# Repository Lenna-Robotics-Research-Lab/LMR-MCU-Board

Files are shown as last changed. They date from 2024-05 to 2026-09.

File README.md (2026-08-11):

# LMR Bardia MCU Board

Open-source control electronics and embedded software for the **Lenna Mobile Robot ONE (LMR v1.1)**, developed by [Lenna Robotics Research Lab](https://github.com/Lenna-Robotics-Research-Lab).

The Bardia board is built around the STM32F407VGT6 and combines motor control, encoder feedback, sensor interfaces, power management, and host-computer communication on one mobile-robotics platform.

<p align="center">
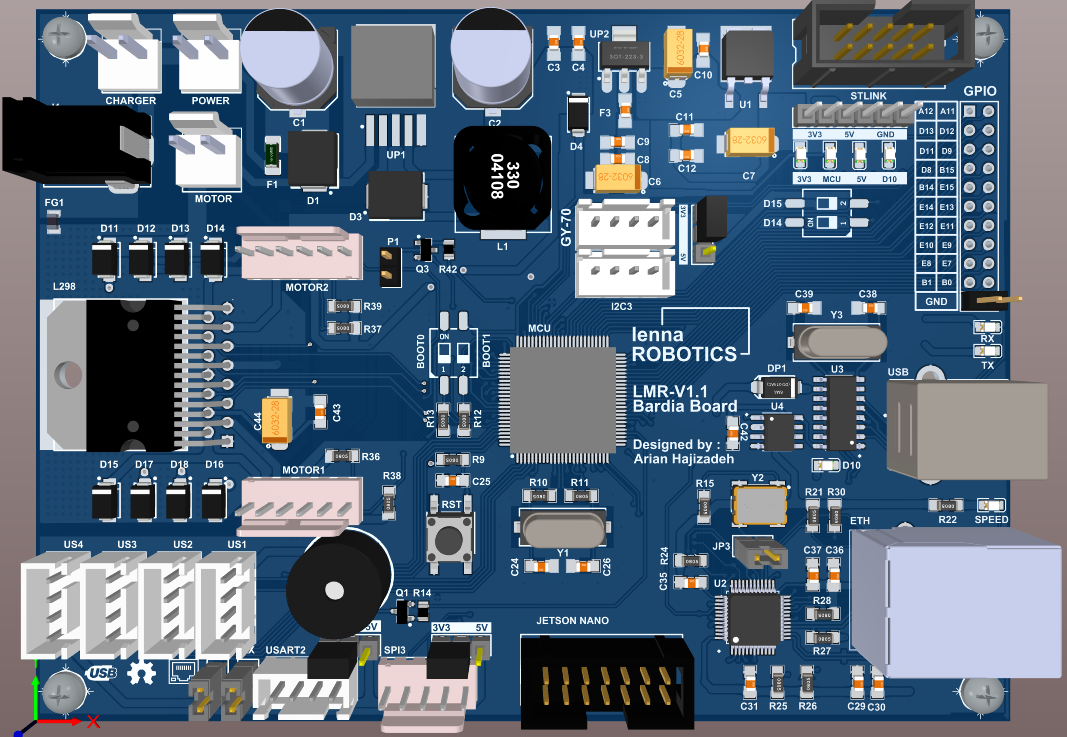
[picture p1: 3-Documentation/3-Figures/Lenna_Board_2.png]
Top view of the LMR Bardia MCU board
  
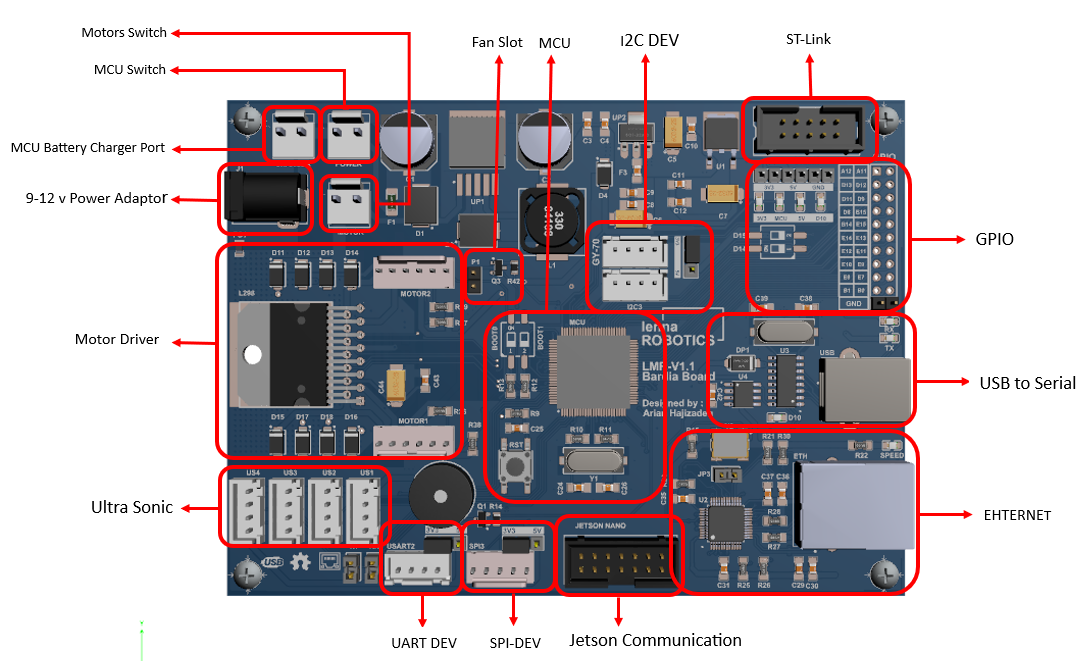
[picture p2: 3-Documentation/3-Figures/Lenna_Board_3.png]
Angled view of the LMR Bardia MCU board
  
</p>

## Contents

- [Main features](#main-features)
- [Quick navigation](#quick-navigation)
- [Repository structure](#repository-structure)
- [Hardware overview](#hardware-overview)
- [Embedded software](#embedded-software)
- [Motor identification and control](#motor-identification-and-control)
- [Host communication](#host-communication)
- [Getting started](#getting-started)
- [License](#license)

## Main features

- STM32F407VGT6 Arm Cortex-M4 microcontroller
- On-board L298 dual H-bridge motor driver
- Quadrature encoder inputs for closed-loop wheel-speed control
- CH340G USB-to-serial interface
- Simultaneous USB and battery connection through the power-management circuit
- Dedicated battery-voltage ADC input
- Dedicated cooling-fan connector
- Four HC-SR04-compatible ultrasonic sensor connectors
- Expansion interfaces:
  - 1x I2C
  - 1x UART
  - 1x SPI
  - 1x CAN
  - 20x GPIO
- Ethernet hardware based on the DP83848 physical-layer transceiver

> [!NOTE]
> Ethernet hardware is present on the board, but Ethernet is not used in the initial LMR v1.1 software release.

## Quick navigation

| Area | Location | Description |
| --- | --- | --- |
| Datasheets | [`1-Resources/1-Datasheets`](./1-Resources/1-Datasheets) | Component datasheets and hardware design references |
| MATLAB simulation | [`2-Design/2-Simulation/MATLAB`](./2-Design/2-Simulation/MATLAB) | Kinematic modelling and motor system identification |
| Altium hardware project | [`2-Design/3-Detailed-Design/1-Electronics/LMR_V1`](./2-Design/3-Detailed-Design/1-Electronics/LMR_V1) | Schematics, PCB layout, and 3D board files |
| STM32 firmware | [`2-Design/3-Detailed-Design/2-Source-Code/Lenna-Bardia-MCU-Board`](./2-Design/3-Detailed-Design/2-Source-Code/Lenna-Bardia-MCU-Board) | STM32CubeIDE project and embedded-software documentation |
| Board figures | [`3-Documentation/3-Figures`](./3-Documentation/3-Figures) | Board photographs, renders, and pinout diagram |
| License | [`LICENSE`](./LICENSE) | Repository license |

## Repository structure

The following tree shows the main project areas. Generated STM32 support files and individual datasheets are omitted for readability.

```text
LMRO-MCU-Board/
├── 1-Resources/
│   └── 1-Datasheets/                 # Component datasheets and references
├── 2-Design/
│   ├── 2-Simulation/
│   │   └── MATLAB/
│   │       ├── Kinematics-Modeling/  # Differential-drive modelling
│   │       └── System-Identification/# Motor identification and control models
│   └── 3-Detailed-Design/
│       ├── 1-Electronics/
│       │   └── LMR_V1/               # Altium schematics, PCB, and 3D models
│       └── 2-Source-Code/
│           └── Lenna-Bardia-MCU-Board/
│               ├── Core/
│               │   ├── Inc/          # Application headers
│               │   ├── Src/          # Application sources
│               │   └── Startup/      # STM32 startup code
│               ├── Drivers/          # STM32 HAL and CMSIS drivers
│               ├── Lenna-Bardia-MCU-Board.ioc
│               └── README.md         # Detailed firmware documentation
├── 3-Documentation/
│   └── 3-Figures/                    # Board images and pinout
├── LICENSE
└── README.md
```

## Hardware overview

### Microcontroller

The STM32F407VGT6 is the central controller of the Bardia board. It was selected for its processing capability, timer resources, encoder support, communication peripherals, Ethernet capability, availability, and cost.

Its peripherals allow the board to connect directly to the robot's motor driver, wheel encoders, IMU, ultrasonic sensors, battery monitor, and high-level computer.

### Motor driver

The on-board L298 dual H-bridge can drive the two DC motors used by the LMR v1.1 differential-drive base. The motor-control firmware generates PWM and direction signals, while the wheel encoders provide feedback to the PID speed controller.

For robots that require additional motors, higher current, or greater precision, an external motor-driver board is recommended.

Noise-reduction measures include:

- **Single-point ground connection:** the motor-driver ground and logic ground are joined at one point through a ferrite bead.
- **EMI reduction:** ground stitching is used around the motor-driver section of the PCB.

### USB-to-serial interface

The USB Type-B connector and CH340G interface provide a direct serial connection to a computer. This connection can be used for debugging, telemetry, and MATLAB/Octave-based experiments. USB can also power the logic circuitry when motor power is not required.

### Power management

The board supports either:

- a three-cell lithium-ion battery pack with an integrated BMS (12.6 V fully charged, 2200 mAh in the original robot); or
- a 5 V USB supply when the motors are not needed.

The power-management circuit allows the battery and USB connection to remain attached simultaneously.

### Board layout

The board pinout and connector assignments are shown below.

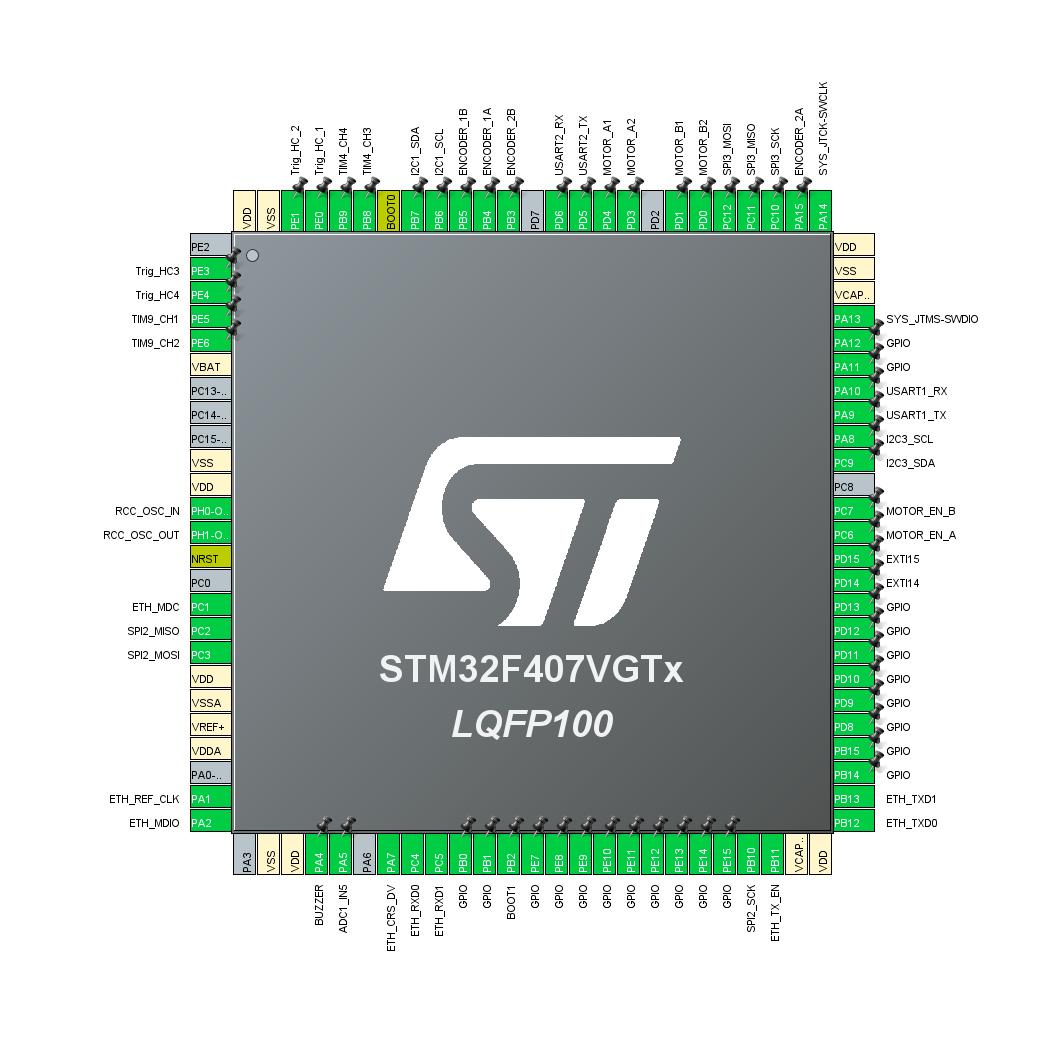
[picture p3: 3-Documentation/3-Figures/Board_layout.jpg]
LMR v1.1 Bardia board pinout


## Embedded software

The STM32 firmware is the low-level control system for the robot. It handles motor actuation, encoder feedback, odometry, IMU acquisition, ultrasonic sensing, battery monitoring, and serial communication with the high-level computer.

The complete STM32CubeIDE project and detailed module documentation are available in the [firmware directory](./2-Design/3-Detailed-Design/2-Source-Code/Lenna-Bardia-MCU-Board).

### Main firmware modules

| Module | Purpose |
| --- | --- |
| `main.c` | Peripheral initialization and application scheduling |
| `motion.c` / `motion.h` | PWM and direction control for the differential-drive motors |
| `pid.c` / `pid.h` | Closed-loop wheel-speed PID controller |
| `odometry.c` / `odometry.h` | Encoder processing, wheel speed, and travelled-distance calculation |
| `imu.c` / `imu.h` | MPU-6050 and HMC5883L acquisition, calibration, and orientation estimation |
| `rosserial.c` / `rosserial.h` | Custom UART packet handling for commands and telemetry |
| `ultrasonic.c` / `ultrasonic.h` | HC-SR04 trigger, echo capture, and distance measurement |
| `mcu_config.h` | Central hardware and application configuration |
| `utilities.c` / `utilities.h` | Shared timing and helper functions |

> [!IMPORTANT]
> Public functions developed by Lenna Robotics Research Lab use the `LRL_` prefix. Private module functions may use a leading underscore, such as `_LRL_...`.

## Motor identification and control

The two ZGA25 motors can respond differently even when they share the same part number and receive the same input. Closed-loop control is therefore required to obtain consistent wheel speeds.

The controller-development workflow uses:

1. the board's USB-to-serial interface to exchange experiment data;
2. MATLAB/Simulink Desktop Real-Time for motor system identification;
3. the identified motor response to support controller design; and
4. an embedded PID controller with encoder feedback to regulate each wheel speed.

The related models are available in [`2-Design/2-Simulation/MATLAB`](./2-Design/2-Simulation/MATLAB).

## IMU

The robot uses a GY-87 module connected through I2C. The module combines an MPU-6050 accelerometer/gyroscope with an HMC5883L magnetometer. Magnetometer data provides an external heading reference that helps reduce yaw drift compared with gyroscope-only estimation.

The firmware provides dedicated initialization, calibration, sensor-reading, and complementary-filter functions in `imu.c` and `imu.h`.

## Host communication

The Bardia board communicates with the robot's high-level computer through UART. The original LMR v1.1 integration used a Jetson Nano; the interface can also be used with another compatible Jetson or Linux host.

A custom Lenna Robotics Research Lab packet protocol carries:

- wheel-speed commands from the host to the MCU; and
- encoder, odometry, IMU, ultrasonic, and board-status telemetry from the MCU to the host.

Low-level control remains on the STM32, while perception, navigation, and other computationally intensive tasks run on the high-level computer.

## Getting started

### Explore the hardware

1. Open [`LMR_V1.PrjPcb`](./2-Design/3-Detailed-Design/1-Electronics/LMR_V1/LMR_V1.PrjPcb) in Altium Designer.
2. Review the individual schematic sheets before connecting external hardware.
3. Use the [board layout](#board-layout) to verify connector pin assignments.

### Build the firmware

1. Install STM32CubeIDE.
2. Import the project from [`2-Design/3-Detailed-Design/2-Source-Code/Lenna-Bardia-MCU-Board`](./2-Design/3-Detailed-Design/2-Source-Code/Lenna-Bardia-MCU-Board).
3. Review the board configuration in `Lenna-Bardia-MCU-Board.ioc` and `Core/Inc/mcu_config.h`.
4. Build the project and flash the STM32F407VGT6 using an ST-LINK-compatible programmer.
5. Read the [firmware README](./2-Design/3-Detailed-Design/2-Source-Code/Lenna-Bardia-MCU-Board/README.md) for module-level details.

> [!CAUTION]
> Verify the supply voltage, motor wiring, encoder wiring, and connector pinout before powering the motors. USB power alone is intended for the logic circuitry, not for driving the motors.

## License

This repository is distributed under the terms in [`LICENSE`](./LICENSE).

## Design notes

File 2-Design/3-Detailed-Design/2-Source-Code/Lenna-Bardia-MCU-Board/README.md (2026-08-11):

# Lenna Mobile Robot ONE — MCU Firmware

This directory contains the embedded firmware for the **Lenna Mobile Robot ONE (LMR)** Bardia MCU Board. The application runs on an **STM32F407VGT6** and provides the robot's low-level, real-time functions:

- closed-loop speed control for two DC motors;
- quadrature-encoder odometry;
- MPU-6050 and HMC5883L sensor acquisition;
- differential-drive motor output;
- ultrasonic-sensor support;
- command and telemetry exchange with the host computer over UART.

For the board design, schematics, PCB files, and full project documentation, return to the [repository README](../../../../README.md).

## Contents

- [Firmware architecture](#firmware-architecture)
- [Runtime schedule](#runtime-schedule)
- [Project structure](#project-structure)
- [Hardware and peripheral map](#hardware-and-peripheral-map)
- [Modules](#modules)
- [Serial communication](#serial-communication)
- [Build and flash](#build-and-flash)
- [Configuration](#configuration)
- [Real-time design rules](#real-time-design-rules)
- [Debugging](#debugging)
- [Coding conventions](#coding-conventions)
- [License](#license)

## Firmware architecture

The firmware uses STM32 HAL drivers and a cooperative main loop. Hardware interrupts signal time-critical events, while command execution, control updates, and sensor acquisition are performed by application code.

```mermaid
flowchart TD
    Host["Host computer"] -->|"UART commands"| Serial["ROS-serial protocol"]
    Serial --> PID["100 Hz speed PID"]
    Encoders["Wheel encoders"] --> Odom["Odometry cache"]
    Odom --> PID
    PID --> Motors["PWM and direction"]
    IMU["GY-87 at 10 Hz"] --> Cache["IMU cache"]
    Odom --> Telemetry["ReadAll telemetry"]
    Cache --> Telemetry
    Telemetry -->|"UART response"| Host
```

The main data paths are:

1. A host command is received through USART1 or USART2.
2. The protocol handler validates the frame and updates the requested state, such as motor-speed references or PID gains.
3. TIM5 schedules the speed-control loop every 10 ms.
4. The PID module reads both encoders, updates the cached wheel measurements, and calculates the left and right motor commands.
5. The motion module applies direction GPIO states and PWM duty cycles.
6. IMU measurements are acquired separately every tenth control cycle.
7. A `ReadAll` request serializes the most recent cached odometry and IMU values without initiating new sensor reads.

## Runtime schedule

| Activity | Nominal rate | Location | Purpose |
|---|---:|---|---|
| TIM5 scheduler | 100 Hz | `main.c` | Raises the control-loop flag every 10 ms |
| Encoder and PID update | 100 Hz | `pid.c` | Measures wheel speed and updates both motor outputs |
| IMU and magnetometer acquisition | 10 Hz | `main.c`, `imu.c` | Refreshes the cached inertial measurements |
| UART reception | Event-driven | `main.c`, `rosserial.c` | Receives framed host commands using interrupts |
| Telemetry response | On request | `rosserial.c` | Sends the latest cached state |

TIM5 has a higher effective interrupt priority than the UART interfaces. Keep interrupt callbacks short and keep all blocking peripheral operations out of interrupt context.

## Project structure

```text
Lenna-Bardia-MCU-Board/
├── Core/
│   ├── Inc/                         Application and generated headers
│   │   ├── mcu_config.h             Board-level pin and protocol definitions
│   │   ├── motion.h                 Motor and differential-drive API
│   │   ├── odometry.h               Encoder and wheel-state API
│   │   ├── pid.h                    Dual-motor PID API and default gains
│   │   ├── imu.h                    MPU-6050/HMC5883L API
│   │   ├── rosserial.h              UART protocol state and commands
│   │   ├── ultrasonic.h             HC-SR04 API
│   │   └── utilities.h              Timing utilities
│   ├── Src/
│   │   ├── main.c                   Initialization, scheduler, and callbacks
│   │   ├── motion.c                 PWM and direction control
│   │   ├── odometry.c               Encoder processing
│   │   ├── pid.c                    Closed-loop wheel-speed control
│   │   ├── imu.c                    IMU, magnetometer, and filtering
│   │   ├── rosserial.c              Packet validation and dispatch
│   │   ├── ultrasonic.c             Ultrasonic measurement
│   │   └── utilities.c              Microsecond delay support
│   └── Startup/                     STM32 startup assembly
├── Drivers/                         STM32F4 HAL and CMSIS
├── .settings/                       STM32CubeIDE project settings
├── Lenna-Bardia-MCU-Board.ioc       STM32CubeMX configuration
├── STM32F407VGTX_FLASH.ld           Flash linker script
├── STM32F407VGTX_RAM.ld             RAM linker script
└── README.md                        Firmware documentation
```

Files such as `gpio.c`, `tim.c`, `usart.c`, and `i2c.c` are generated from the `.ioc` configuration. Application-specific behavior is concentrated in `main.c` and the `LRL_` modules.

## Hardware and peripheral map

| Peripheral | Assignment | Firmware use |
|---|---|---|
| STM32 | STM32F407VGT6, LQFP100 | Main controller |
| TIM2 | Encoder mode | Left wheel encoder |
| TIM3 | Encoder mode | Right wheel encoder |
| TIM8 CH1 | PWM | Right motor |
| TIM8 CH2 | PWM | Left motor |
| TIM5 | Periodic interrupt | 10 ms control scheduler |
| TIM4 | Input capture | Ultrasonic echo timing |
| TIM1 | Base timer | Microsecond delay utility |
| USART1 | 115200, 8-N-1 | On-board USB-to-serial interface |
| USART2 | 115200, 8-N-1 | Host/Jetson interface |
| I2C3 | 100 kHz | GY-87 IMU and magnetometer |
| ADC1 | Analog input | Battery-level measurement support |

The current differential-drive configuration in `main.c` uses a wheel radius of **32.5 mm**, a wheel separation of **180 mm**, and an encoder period of **48,960 counts**.

## Modules

### Motion control

[`motion.c`](Core/Src/motion.c) converts signed duty-cycle commands into motor direction and PWM output.

| Function | Purpose |
|---|---|
| `LRL_Motion_MotorSpeed()` | Controls one motor from -100% to +100% duty cycle |
| `LRL_Motion_Control()` | Applies independent left and right motor commands |
| `LRL_Motion_MotorTest()` | Runs a blocking motor test sequence for bench testing |

### PID controller

[`pid.c`](Core/Src/pid.c) contains a single controller state with independent gains and internal values for the two wheels. `LRL_PID_Update()` performs the encoder measurement, calculates both control signals, applies saturation, and supports anti-windup.

Default gains, saturation limits, and the 10 ms sampling time are defined in [`pid.h`](Core/Inc/pid.h). Gains can also be changed through the serial protocol.

### Odometry

[`odometry.c`](Core/Src/odometry.c) reads TIM2 and TIM3, handles counter wraparound, calculates signed wheel velocity, and updates incremental wheel distance.

`LRL_Odometry_ReadAngularSpeed()` owns the encoder-history update. During normal closed-loop operation it is called by `LRL_PID_Update()`, and the resulting values in `odom.vel` and `odom.dist` act as the telemetry cache.

### IMU and magnetometer

[`imu.c`](Core/Src/imu.c) supports the GY-87 module:

- MPU-6050 accelerometer and gyroscope initialization;
- accelerometer and gyroscope calibration;
- HMC5883L magnetometer initialization and heading calculation;
- complementary filtering for roll and pitch.

The main loop refreshes the IMU cache at 10 Hz. Communication functions read this cache; they do not perform I2C transactions.

### ROS-serial protocol

[`rosserial.c`](Core/Src/rosserial.c) implements the custom binary protocol used by the host-side ROS integration. Despite the module name, this is a project-specific protocol with ROS-style framing, not the standard ROS `rosserial` client library.

The module supports both configured UART interfaces through separate `rosserial_cfgType` instances.

### Ultrasonic sensors

[`ultrasonic.c`](Core/Src/ultrasonic.c) provides trigger, input-capture, overflow, and distance-reading functions for HC-SR04 sensors. The callbacks are available, but the relevant callback code in `main.c` must be enabled when ultrasonic sensing is used.

### Utilities

[`utilities.c`](Core/Src/utilities.c) provides the timer-backed `LRL_Delay_Us()` helper used for short microsecond delays.

## Serial communication

### Interfaces

| Interface | Handle | Intended connection |
|---|---|---|
| USB-to-serial | `huart1` / USART1 | Development computer |
| Host serial | `huart2` / USART2 | Jetson or another high-level controller |

Both interfaces use **115200 baud, 8 data bits, no parity, and 1 stop bit**.

### Frame format

| Byte(s) | Field | Description |
|---|---|---|
| 0 | Sync 1 | `0xFF` |
| 1 | Protocol version / Sync 2 | `0xFE` |
| 2–3 | Payload length | 16-bit little-endian length |
| 4 | Header checksum | Validates the length field |
| 5–6 | Function ID | Two-byte command identifier; current dispatch uses the low byte |
| 7…N | Command data | Function-specific payload |
| Last | Data checksum | Validates the function ID and data |

### Commands

| ID | Command | MCU behavior |
|---:|---|---|
| `0x00` | Query | Echoes the received frame for a link test |
| `0x01` | ReadAll | Returns cached wheel, IMU, and heading data |
| `0x02` | SetPID | Updates left or right PID gains |
| `0x03` | GetPID | Returns the selected motor's PID gains |
| `0x04` | MotorSpeed | Updates the signed left and right wheel-speed references |

The protocol parser validates sync bytes and both checksums. Invalid frames generate an error response. Refer to the header comment in [`rosserial.c`](Core/Src/rosserial.c) for byte-level examples.

## Build and flash

### Requirements

- STM32CubeIDE;
- an ST-LINK programmer/debugger;
- the Bardia MCU Board or equivalent STM32F407VGT6 target;
- a suitable board power supply;
- optional serial terminal for communication tests.

The repository already contains the STM32 HAL and CMSIS dependencies under `Drivers/`; no separate package installation is required.

### STM32CubeIDE workflow

1. Clone the repository:

   ```bash
   git clone https://github.com/Lenna-Robotics-Research-Lab/LMRO-MCU-Board.git
   ```

2. In STM32CubeIDE, select **File → Open Projects from File System**.
3. Select this `Lenna-Bardia-MCU-Board` directory as the project root.
4. Allow STM32CubeIDE to import the existing project configuration.
5. Select the **Debug** or **Release** build configuration and build the project.
6. Connect ST-LINK to SWDIO, SWCLK, GND, and the appropriate reference voltage.
7. Use **Run** or **Debug** to program the MCU.

Before connecting motors, verify the supply voltage, motor wiring, encoder wiring, and direction convention. For initial tests, keep the wheels raised or mechanically unloaded and ensure an emergency power-disconnect method is available.

## Configuration

| Setting | Location |
|---|---|
| Board GPIO and basic protocol constants | [`mcu_config.h`](Core/Inc/mcu_config.h) |
| MCU pins, clocks, timers, and peripheral generation | [`Lenna-Bardia-MCU-Board.ioc`](Lenna-Bardia-MCU-Board.ioc) |
| Motor mapping and robot geometry | [`main.c`](Core/Src/main.c) |
| PID gains, limits, and sample time | [`pid.h`](Core/Inc/pid.h) |
| UART selection and protocol limits | [`rosserial.h`](Core/Inc/rosserial.h) |
| IMU addresses, ranges, and filter constants | [`imu.h`](Core/Inc/imu.h) |

When regenerating code with STM32CubeMX, keep application changes inside the generated `USER CODE BEGIN` / `USER CODE END` sections. Review the generated interrupt priorities after regeneration.

## Real-time design rules

These rules are essential for stable motor control:

1. **The PID loop owns encoder sampling.** During closed-loop operation, only `LRL_PID_Update()` should call `LRL_Odometry_ReadAngularSpeed()`. Other modules consume the cached values.
2. **`ReadAll` must remain read-only with respect to sensors.** It may copy cached `odom` and `imu` fields, build a packet, and transmit it. Do not add `LRL_IMU_MPUReadAll()`, `LRL_IMU_MagReadHeading()`, or a new odometry measurement to this function.
3. **Do not perform blocking I2C work in UART callbacks.** Blocking sensor reads can delay the 10 ms control schedule and produce visible motor-speed jumps.
4. **Keep interrupt callbacks short.** Receive or store data, update a flag, and return. Perform packet dispatch and peripheral work in the main loop.
5. **Keep telemetry transmission asynchronous where practical.** `ReadAll` currently uses `HAL_UART_Transmit_IT()` so the 34-byte response does not block the controller for the full wire time.
6. **Preserve priority ordering.** TIM5 must be able to pre-empt UART handling. The application sets TIM5 to priority 1 and USART2 to priority 2; lower numbers represent higher urgency on STM32.
7. **Keep scheduled work bounded.** `pid_tim_flag` is a binary flag, so a main-loop operation that lasts longer than one 10 ms period can collapse multiple timer events into one update.

The intended ownership model is:

```text
PID update:  encoders -> odometry cache -> controller -> motor output
IMU task:    I2C sensors -> IMU cache
ReadAll:     odometry cache + IMU cache -> UART packet
```

## Debugging

### Motors jump when telemetry is requested

Check that `LRL_ROSSerial_ReadAll()` only packages cached fields. Fresh I2C or encoder acquisition in the telemetry path disturbs the controller timing.

### Motors do not move

- Confirm that TIM8 PWM channels are started.
- Confirm that a non-zero speed reference was received.
- Inspect `mypid.Ref_Vel_l`, `mypid.Ref_Vel_r`, and both control signals.
- Verify motor direction GPIOs and the external power supply.

### Wheel speed is incorrect or reversed

- Verify that TIM2 is connected to the left encoder and TIM3 to the right encoder.
- Check the encoder channel polarity and wiring.
- Confirm `MAX_ARR`, `TICK2RPM`, and the left/right direction conventions.

### Serial commands are ignored

- Confirm 115200, 8-N-1 on the host.
- Verify that the frame starts with `0xFF 0xFE`.
- Check the header and data checksums.
- Confirm that the host is connected to the intended UART.
- Inspect `err_hdl`, `packetReceived`, `headerValid`, and `dataValid`.

### IMU values do not update

- Verify the GY-87 connection to I2C3.
- Confirm sensor addresses and pull-up resistors.
- Check HAL return values during initialization and reads.
- Ensure the 10 Hz acquisition block remains enabled in `main.c`.

## Coding conventions

- Public laboratory functions use the `LRL_<Module>_<Function>` naming pattern.
- Module headers live in `Core/Inc`; implementations live in `Core/Src`.
- Configuration structures commonly use the `_cfgType` suffix; state structures use `_statetype`.
- Constants and macros use uppercase names with underscores.
- Internal module helpers may begin with an underscore, such as `_LRL_Clear_Buffer()`.
- Public functions and modules should use Doxygen-compatible comments.
- Hardware mappings belong in `mcu_config.h`, `main.h`, or the `.ioc` file rather than being duplicated throughout the application.

## License

This firmware is distributed under the repository's [GNU General Public License v3.0](../../../../LICENSE).

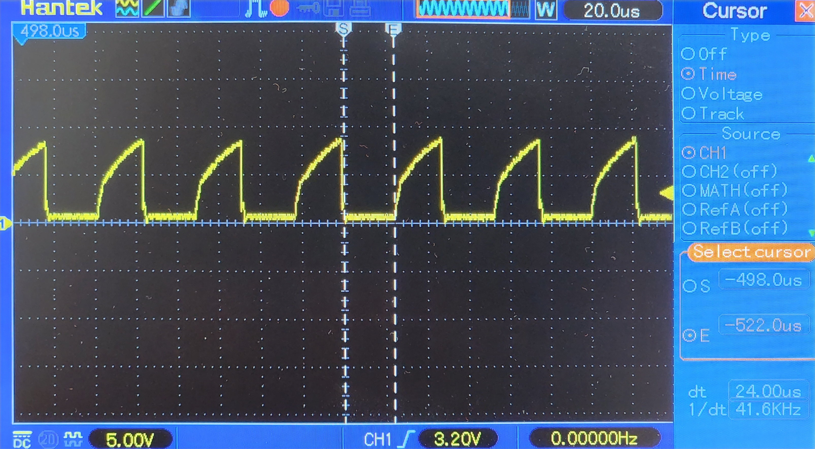
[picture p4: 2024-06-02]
2-Design/2-Simulation/MATLAB/System-Identification/pin-1-voltage.jpg

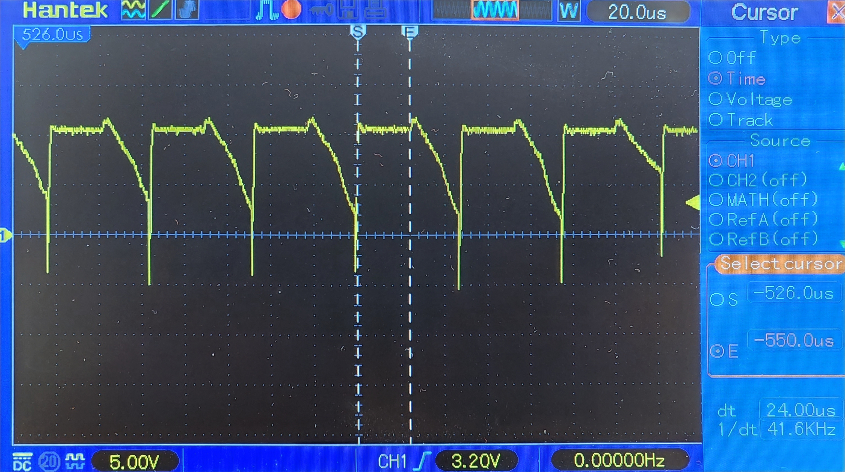
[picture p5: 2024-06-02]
2-Design/2-Simulation/MATLAB/System-Identification/pin-2-voltage.jpg

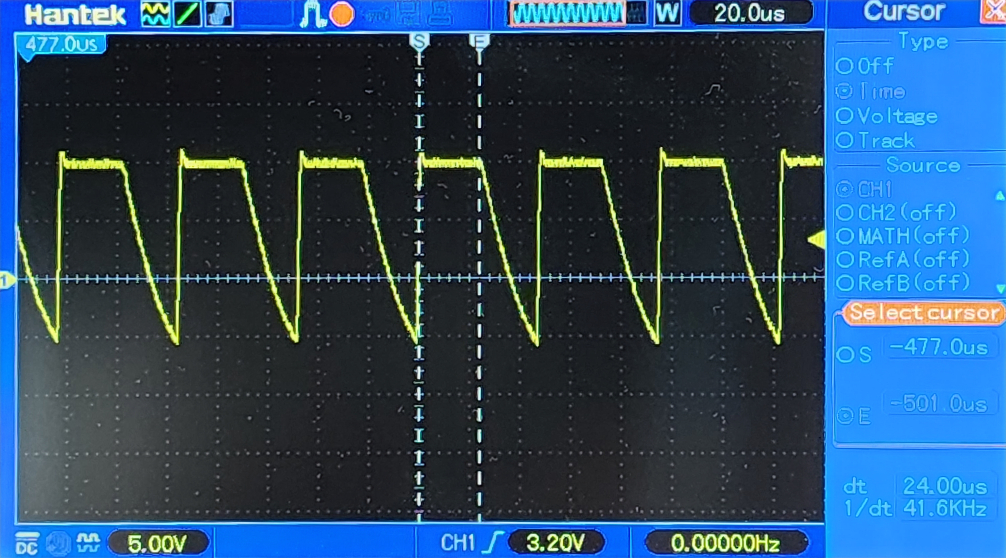
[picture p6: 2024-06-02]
2-Design/2-Simulation/MATLAB/System-Identification/motor-voltage.jpg

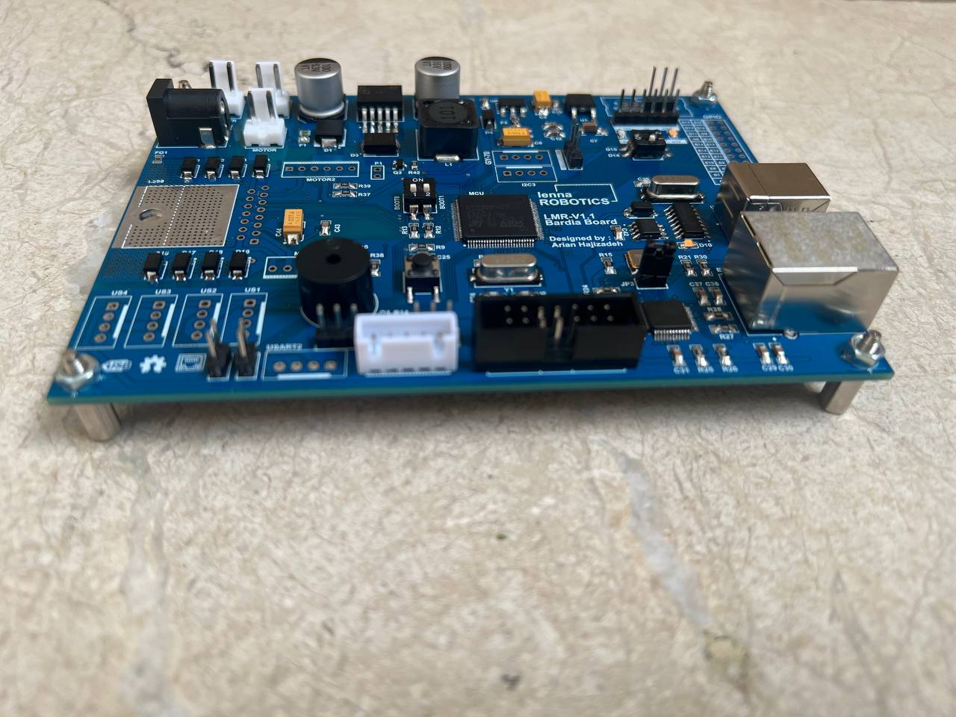
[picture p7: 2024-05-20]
3-Documentation/3-Figures/board_image.jpg

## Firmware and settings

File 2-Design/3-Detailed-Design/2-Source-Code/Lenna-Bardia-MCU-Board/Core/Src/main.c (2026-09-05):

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
/* Includes ------------------------------------------------------------------*/
#include "main.h"
#include "adc.h"
#include "eth.h"
#include "i2c.h"
#include "spi.h"
#include "tim.h"
#include "usart.h"
#include "gpio.h"

/* USER CODE BEGIN Includes */
#include "stdio.h"
#include "stdlib.h"
#include "stdbool.h"
#include "ultrasonic.h"
#include "utilities.h"
#include "motion.h"
#include "pid.h"
#include "math.h"
#include "odometry.h"
#include "mcu_config.h"
#include "imu.h"
#include "rosserial.h"



/* USER CODE END Includes */

/* USER CODE BEGIN PM */
#define PUTCHAR_PROTOTYPE int __io_putchar(int ch)

/* USER CODE END PM */


/* USER CODE BEGIN PV */

// message buffer for Initialization on High-level board
uint8_t msgBuffer[32] = " Lenna Robotics Research Lab. \r\n";

// Protocol packet size limits
uint8_t min_len_packet = 8;
uint8_t max_len_packet = 32;

//protocol Settings
//uint8_t protocol_data[144] = {0};
bool flag_uart_cb = 0;
bool flag_remain_packet = 1;

uint8_t total_pkt_length = 0;
uint8_t remain_pkt_length = 0;

unsigned short temp_crc = 0;

char MSG[64];

// LENNA for the ack
uint8_t txBuffer[144]; //= {0xFF, 0xFF, 0x05, 0xA0, 0xAB, 0xCD, 0xB4, 0xFC};



// step given by MATLAB code
uint8_t input_speed ;

// temp variables for odom
uint16_t left_enc_temp = 0, right_enc_temp = 0 , right_enc_diff = 0, left_enc_diff = 0;

// direction set
int8_t dir_right,dir_left;

//odom variables
uint16_t encoder_tick[2] = {0};
float angular_speed_left,angular_speed_right;
uint16_t tst;

uint8_t flag_tx = 0, pid_tim_flag = 0, dir_flag = 0;

uint8_t serial_flag = 0;


uint8_t test_flag = 0;


// ####################   Motor struct Value Setting   ###################
const motor_cfgType motor_right =
{
	MOTOR_PORT,
	MOTOR1_A_PIN,
	MOTOR_PORT,
	MOTOR1_B_PIN,
	&htim8,
	TIM_CHANNEL_1,
	1000,
	//1
};
const motor_cfgType motor_left =
{
	MOTOR_PORT,
	MOTOR2_A_PIN,
	MOTOR_PORT,
	MOTOR2_B_PIN,
	&htim8,
	TIM_CHANNEL_2,
	1000,
	//-1
};

// ####################   Ultra-Sonic struct Value Setting   ###################

const diffDrive_cfgType diff_robot =
{
	motor_right,
	motor_left,
	32.5,
	180
};

// ####################   ODOMETRY  ###################
const imu_cfgType gy87 =
{
	&hi2c3
};

const encoder_cfgType enc_right =
{
	&htim3,
	48960,
	0.1225f		// 6000/48960
};

const encoder_cfgType enc_left =
{
	&htim2,
	48960,
	0.1225f		// 6000/48960
};

odom_cfgType odom =
{
//	imu,
	enc_right,
	enc_left,
	diff_robot
};

imu_statetype imu =
{
	gy87
};

const ultrasonic_cfgType us_front =
{
	US1_TRIG_PORT,
	US1_TRIG_PIN,
	&htim4,
	TIM4,
	TIM_CHANNEL_3,
	168,
	1
};

// ####################   PID struct Value Setting   ###################

// definitions concerning PID gain values are made in the main.h header file

/* alternative PID
pid_cfgType2 pid_motor_left =
{
	.Kp 					= Proportional_Gain_LEFT_MOTOR,
	.Ki 					= Integral_Gain_LEFT_MOTOR,
	.Kd 					= Derivative_Gain_LEFT_MOTOR,
	.Ts 					= Sampling_Time,
	.Lower_Limit_Saturation = Lower_Saturation_Limit,
	.Upper_Limit_Saturation = Upper_Saturation_Limit,
	.Wind_Up_Amount			= 1,
};

pid_cfgType2 pid_motor_right =
{
	.Kp 					= Proportional_Gain_LEFT_MOTOR,
	.Ki 					= Integral_Gain_LEFT_MOTOR,
	.Kd 					= Derivative_Gain_LEFT_MOTOR,
	.Ts 					= Sampling_Time,
	.Lower_Limit_Saturation = Lower_Saturation_Limit,
	.Upper_Limit_Saturation = Upper_Saturation_Limit,
	.Wind_Up_Amount			= 1,
};
*/

pid_cfgType mypid;

uint8_t _pid_counter = 0; // this counter is added to reduce the effect of IMU polling temporary fix if you are not using IMU keep this 0
// ####################   Packet struct Value Setting   ###################


rosserial_cfgType ros_packet;
rosserial_cfgType usb2serial_packet;

int16_t val_x;
int16_t val_y;
int16_t val_z;
float val_heading;

uint8_t testBuffer[10]; // buffer for using test uart packet

uint8_t _temp_flag = 0;

//uint8_t protocol_buffer[256]; // the buffer used for the protocol

/* USER CODE END PV */

void SystemClock_Config(void);
/* USER CODE BEGIN 0 */

// ####################   UART Tx -> printf   ####################
PUTCHAR_PROTOTYPE
{
  /* Place your implementation of fputc here */
  /* e.g. write a character to the USART1 and Loop until the end of transmission */
  HAL_UART_Transmit(&huart1, (uint8_t *)&ch, 1, 0xFFFF);

  return ch;
}

/* USER CODE END 0 */

/**
  * @brief  The application entry point.
  * @retval int
  */
int main(void)
{
  /* MCU Configuration--------------------------------------------------------*/

  /* Reset of all peripherals, Initializes the Flash interface and the Systick. */
  HAL_Init();

  /* Configure the system clock */
  SystemClock_Config();

  /* Initialize all configured peripherals */
  MX_GPIO_Init();
  MX_ADC1_Init();
  MX_ETH_Init();
  MX_I2C1_Init();
  MX_I2C3_Init();
  MX_SPI2_Init();
  MX_SPI3_Init();
  MX_TIM2_Init();
  MX_TIM3_Init();
  MX_TIM4_Init();
  MX_TIM8_Init();
  MX_TIM9_Init();
  MX_USART1_UART_Init();
  MX_USART2_UART_Init();
  MX_TIM1_Init();
  MX_TIM5_Init();
  /* USER CODE BEGIN 2 */

  // HAL function Initializations
  HAL_TIM_PWM_Start(&htim8, TIM_CHANNEL_1);
  HAL_TIM_PWM_Start(&htim8, TIM_CHANNEL_2);
  HAL_TIM_Encoder_Start(&htim3, TIM_CHANNEL_ALL);
  HAL_TIM_Encoder_Start(&htim2, TIM_CHANNEL_ALL);
  HAL_TIM_Base_Init(&htim5);
  HAL_TIM_Base_Start_IT(&htim5);
  HAL_I2C_Init(&hi2c3);


// #################### Initializations   ####################

//  /* main code initialization

//  LRL_PID_Init(&pid_motor_left,  1);
//  LRL_PID_Init(&pid_motor_right, 1);

  HAL_GPIO_WritePin(BLINK_LED_PORT, BLINK_LED_PIN, 1);

  LRL_PID_Init(&mypid, 1);

  HAL_NVIC_SetPriority(TIM5_IRQn, 1, 0);
  HAL_NVIC_SetPriority(USART2_IRQn, 2, 0);

  LRL_Odometry_Init(&odom);

//  LRL_IMU_MPUInit(&imu);

//  LRL_IMU_MagInit(&imu);

  LRL_ROSSerial_Init(&usb2serial_packet, USB2SERIAL_UART_HANDLER);
  LRL_ROSSerial_Init(&ros_packet, JETSON_UART_HANDLER);

  HAL_GPIO_WritePin(BLINK_LED_PORT, BLINK_LED_PIN, 0);

  odom.dist.right = 0;
  odom.dist.left = 0;

  /* USER CODE END 2 */

  /* Infinite loop */
  /* USER CODE BEGIN WHILE */
  while (1)
  {
	  if(pid_tim_flag == 1)
	  {
		 if(_temp_flag == 1)
		 {
			 LRL_ROSSerial_Data_Handle(&ros_packet, &imu, &odom, &mypid);
		 }
		 else if(_temp_flag == 2)
		 {
			 LRL_ROSSerial_Data_Handle(&usb2serial_packet, &imu, &odom, &mypid);
		 }
//		 mypid.Ref_Vel_l = 150;
//		 mypid.Ref_Vel_r = 150;
		 LRL_PID_Update(&mypid, &odom);
		 LRL_Motion_Control(diff_robot, mypid.Control_Signal_l,mypid.Control_Signal_r);

//		 if(_pid_counter == 10){
//			 _pid_counter = 0;
//		     LRL_IMU_MPUReadAll(&imu);
//		     LRL_IMU_MagReadHeading(&imu);
//		     if(!odom.is_pid)
//		     {
//		     	LRL_Odometry_ReadAngularSpeed(&odom);
//		     }
//		 }

		 /* Alternative version for PID
		 LRL_Odometry_ReadAngularSpeed(&odom);
		 LRL_PID_Update(&pid_motor_left, odom.vel.left, 70);
		 LRL_PID_Update(&pid_motor_right, odom.vel.right,70);
		 */

		 /*motor test
		 LRL_Motion_MotorTest(diff_robot);
		 */

		 pid_tim_flag = 0;
	  }

    /* USER CODE END WHILE */

    /* USER CODE BEGIN 3 */
  }
  /* USER CODE END 3 */
}

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
/* USER CODE BEGIN 4 */

// CRC

// ####################   Ultra Sonic Callback   ####################

/*
void HAL_TIM_IC_CaptureCallback(TIM_HandleTypeDef *htim)
{
	// TIMER Input Capture Callback
	LRL_US_TMR_IC_ISR(htim, us_front);
}
*/

// ####################   UART Receive Callback   ####################

void HAL_UART_RxCpltCallback(UART_HandleTypeDef *huart){

	if(huart == ros_packet.huart)
	{

		LRL_ROSSerial_Rx(&ros_packet);
		_temp_flag = 1;
	}
	else if  (huart == usb2serial_packet.huart)
	{
		LRL_ROSSerial_Rx(&usb2serial_packet);
		_temp_flag = 2;
//	HAL_GPIO_WritePin(BLINK_LED_PORT, BLINK_LED_PIN, 1); // this is for testing purposes
	}



}

// ####################   Timer To Creat 0.01 Delay Callback   ####################

void HAL_TIM_PeriodElapsedCallback(TIM_HandleTypeDef* htim){
	if(htim == &htim5)
	{
		_pid_counter ++;
		pid_tim_flag = 1;
	}

}

// ####################   Timer Callback   ####################

/* USER CODE END 4 */
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


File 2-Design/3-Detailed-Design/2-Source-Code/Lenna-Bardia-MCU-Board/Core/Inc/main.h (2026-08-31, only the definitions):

#define TRIG_HC_3_Pin GPIO_PIN_3
#define TRIG_HC_3_GPIO_Port GPIOE
#define TRIG_HC_4_Pin GPIO_PIN_4
#define TRIG_HC_4_GPIO_Port GPIOE
#define ECHO_HC_3_Pin GPIO_PIN_5
#define ECHO_HC_3_GPIO_Port GPIOE
#define ECHO_HC_4_Pin GPIO_PIN_6
#define ECHO_HC_4_GPIO_Port GPIOE
#define JET_SPI_MISO_Pin GPIO_PIN_2
#define JET_SPI_MISO_GPIO_Port GPIOC
#define JET_SPI_MOSI_Pin GPIO_PIN_3
#define JET_SPI_MOSI_GPIO_Port GPIOC
#define Buzzer_Pin GPIO_PIN_4
#define Buzzer_GPIO_Port GPIOA
#define Battery_ADC_Pin GPIO_PIN_5
#define Battery_ADC_GPIO_Port GPIOA
#define JET_SPI_SCK_Pin GPIO_PIN_10
#define JET_SPI_SCK_GPIO_Port GPIOB
#define MOTOR1_PWM_Pin GPIO_PIN_6
#define MOTOR1_PWM_GPIO_Port GPIOC
#define MOTOR2_PWM_Pin GPIO_PIN_7
#define MOTOR2_PWM_GPIO_Port GPIOC
#define BUS_SDA_Pin GPIO_PIN_9
#define BUS_SDA_GPIO_Port GPIOC
#define BUS_SCL_Pin GPIO_PIN_8
#define BUS_SCL_GPIO_Port GPIOA
#define USB2Serial_TX_Pin GPIO_PIN_9
#define USB2Serial_TX_GPIO_Port GPIOA
#define USB2Serial_RX_Pin GPIO_PIN_10
#define USB2Serial_RX_GPIO_Port GPIOA
#define ENCODER2_A_Pin GPIO_PIN_15
#define ENCODER2_A_GPIO_Port GPIOA
#define MOTOR2_B_Pin GPIO_PIN_0
#define MOTOR2_B_GPIO_Port GPIOD
#define MOTOR2_A_Pin GPIO_PIN_1
#define MOTOR2_A_GPIO_Port GPIOD
#define MOTOR1_B_Pin GPIO_PIN_3
#define MOTOR1_B_GPIO_Port GPIOD
#define MOTOR1_A_Pin GPIO_PIN_4
#define MOTOR1_A_GPIO_Port GPIOD
#define ENCODER2_B_Pin GPIO_PIN_3
#define ENCODER2_B_GPIO_Port GPIOB
#define ENCODER1_A_Pin GPIO_PIN_4
#define ENCODER1_A_GPIO_Port GPIOB
#define ENCODER1_B_Pin GPIO_PIN_5
#define ENCODER1_B_GPIO_Port GPIOB
#define JET_I2C_SCL_Pin GPIO_PIN_6
#define JET_I2C_SCL_GPIO_Port GPIOB
#define JET_I2C_SDA_Pin GPIO_PIN_7
#define JET_I2C_SDA_GPIO_Port GPIOB
#define ECHO_HC_1_Pin GPIO_PIN_8
#define ECHO_HC_1_GPIO_Port GPIOB
#define ECHO_HC_2_Pin GPIO_PIN_9
#define ECHO_HC_2_GPIO_Port GPIOB
#define TRIG_HC_1_Pin GPIO_PIN_0
#define TRIG_HC_1_GPIO_Port GPIOE
#define TRIG_HC_2_Pin GPIO_PIN_1
#define TRIG_HC_2_GPIO_Port GPIOE
#define rad2deg 57.2958
#define Speed2PWM_Rate (75/218.0f)
#define Tick2RMP_Rate 6000/48960

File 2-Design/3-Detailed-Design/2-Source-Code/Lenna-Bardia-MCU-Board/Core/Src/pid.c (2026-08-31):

/**
 * @file pid.c
 * @brief This module provides a PID (Proportional-Integral-Derivative) controller implementation.
 *
 * It includes functions for initializing the controller, updating the control
 * signal based on sensor feedback, and handling anti-windup and saturation.
 *
 * @author Lenna Robotics Research Laboratory, Autonomous Systems Research Branch, Iran University of Science and Technology
 * @date October 11, 2025
 * @version 1.0
 * @link https://github.com/Lenna-Robotics-Research-Lab
 */

#include <mcu_config.h>
#include "pid.h"
#include "odometry.h"
#include "main.h"
#include "stdlib.h"


/**
 * @brief Initializes the PID controller parameters.
 * @param pid_cfg Pointer to the PID configuration structure.
 * @param AntiWindup Enables or disables the anti-windup feature (1 for enabled, 0 for disabled).
 *
 * This function resets all PID state variables and sets the initial configuration,
 * including the anti-windup flag.
 */
void LRL_PID_Init(pid_cfgType *pid, uint8_t AntiWindup)
{
    pid->Kp_r = Proportional_Gain_RIGHT_MOTOR;
    pid->Ki_r = Integral_Gain_RIGHT_MOTOR;
    pid->Kd_r = Derivative_Gain_RIGHT_MOTOR;

    pid->Kp_l = Proportional_Gain_LEFT_MOTOR;
    pid->Ki_l = Integral_Gain_LEFT_MOTOR;
    pid->Kd_l = Derivative_Gain_LEFT_MOTOR;

    pid->Ts = Sampling_Time;

    pid->Lower_Limit_Saturation = Lower_Saturation_Limit;
    pid->Upper_Limit_Saturation = Upper_Saturation_Limit;

    pid->Integrator_Amount_r = 0.0f;
    pid->Integrator_Amount_l = 0.0f;
    pid->Differentiator_Amount_r = 0.0f;
    pid->Differentiator_Amount_l = 0.0f;

    pid->Prev_Measurement_r = 0;
    pid->Prev_Measurement_l = 0;
    pid->Prev_Error_r = 0.0f;
    pid->Prev_Error_l = 0.0f;

    pid->Error_r = 0.0f;
    pid->Error_l = 0.0f;
    pid->Wind_Up_Amount_r = 0.0f;
    pid->Wind_Up_Amount_l = 0.0f;

    pid->Control_Signal_r = 0;
    pid->Control_Signal_l = 0;

    pid->Ref_Vel_r = 0;
    pid->Ref_Vel_l = 0;
    pid->Prev_Direction_r = 0;
    pid->Prev_Direction_l = 0;

    pid->Anti_windup_EN = AntiWindup;
}


/**
 * @brief Updates the PID control signal.
 * @param pid_cfg Pointer to the PID configuration structure.
 * @param measurement The current measured value (e.g., motor speed).
 * @param set_point The desired set point.
 *
 * This function calculates the error and then computes the proportional, integral,
 * and derivative terms to generate a new control signal. It also handles
 * direction, anti-windup, and output saturation.
 */

static float LRL_PID_ClampFloat(
    float value,
    float minimum,
    float maximum)
{
    if (value > maximum)
        return maximum;

    if (value < minimum)
        return minimum;

    return value;
}


static int8_t LRL_PID_Sign(int16_t value)
{
    return (value > 0) - (value < 0);
}


static int8_t LRL_PID_UpdateWheel(
    float kp,
    float ki,
    float sample_time,
    int16_t reference_rpm,
    int16_t measured_rpm,
    float *integrator,
    float *previous_error,
    float *current_error,
    int8_t *previous_direction,
    uint8_t anti_windup_enabled)
{
    int8_t direction = LRL_PID_Sign(reference_rpm);

    /*
     * A zero reference means zero PWM. Clear the stored controller
     * state so that the next command cannot inherit old integral action.
     */
    if (direction == 0)
    {
        *integrator = 0.0f;
        *previous_error = 0.0f;
        *current_error = 0.0f;
        *previous_direction = 0;
        return 0;
    }

    /*
     * Reset the controller when the commanded wheel direction changes.
     * This prevents a positive-command integrator from kicking the motor
     * after receiving a negative command, or vice versa.
     */
    if (
        *previous_direction != 0 &&
        direction != *previous_direction)
    {
        *integrator = 0.0f;
        *previous_error = 0.0f;
    }

    /*
     * Preserve reference_rpm's sign, but run the controller on speed
     * magnitudes, matching the working Lenna-Mobile-Robot-ONE firmware.
     */
    float reference_magnitude =
        (float)abs((int)reference_rpm);

    float measurement_magnitude =
        (float)abs((int)measured_rpm);

    float error =
        (reference_magnitude - measurement_magnitude) *
        Speed2PWM_Rate;

    /*
     * Preserve the original firmware's effective integral behavior.
     * Do not add a 0.5 factor yet because doing so changes the effective
     * Ki and would require retuning.
     */
    float candidate_integrator =
        *integrator +
        sample_time * ki * (error + *previous_error);

    float candidate_output =
        kp * error + candidate_integrator;

    /*
     * Conditional integration:
     * - Integrate normally inside the permitted PWM range.
     * - When saturated, integrate only if the error moves the controller
     *   back toward the valid range.
     */
    uint8_t allow_integration =
        !anti_windup_enabled ||
        (
            candidate_output >= 0.0f &&
            candidate_output <= 100.0f
        ) ||
        (
            candidate_output > 100.0f &&
            error < 0.0f
        ) ||
        (
            candidate_output < 0.0f &&
            error > 0.0f
        );

    if (allow_integration)
    {
        *integrator = candidate_integrator;
    }

    float output_magnitude =
        kp * error + *integrator;

    output_magnitude = LRL_PID_ClampFloat(
        output_magnitude,
        0.0f,
        100.0f
    );

    *current_error = error;
    *previous_error = error;
    *previous_direction = direction;

    /*
     * Convert only after saturation. Adding 0.5 performs positive
     * rounding instead of truncation.
     */
    int8_t pwm_magnitude =
        (int8_t)(output_magnitude + 0.5f);

    return (int8_t)(direction * pwm_magnitude);
}
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

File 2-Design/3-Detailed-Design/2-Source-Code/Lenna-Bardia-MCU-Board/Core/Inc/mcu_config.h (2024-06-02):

/*
 * mcu_config.h
 *
 *  Created on: Oct 11, 2023
 *      Author: Lenna Robotics Research Laboratory
 *      		Autonomous Systems Research Branch
 *				Iran University of Science and Technology
 *		GitHub:	github.com/Lenna-Robotics-Research-Lab
 */

#define BUZZER_PORT 	GPIOA
#define Buzzer_PIN 		GPIO_PIN_4

#define BLINK_LED_PORT 	GPIOD
#define BLINK_LED_PIN 	GPIO_PIN_10

//=========================================== BAT ADC =========================================

#define BAT_ADC_PORT 	GPIOA
#define BAT_ADC_PIN 	GPIO_PIN_5

//=========================================== MOTOR ===========================================

#define MOTOR1_EN_PORT 	GPIOC
#define MOTOR1_EN_PIN 	GPIO_PIN_6
#define MOTOR2_EN_PORT 	GPIOC
#define MOTOR2_EN_PIN 	GPIO_PIN_7

#define MOTOR_PORT 		GPIOD
#define MOTOR1_A_PIN 	GPIO_PIN_4
#define MOTOR1_B_PIN 	GPIO_PIN_3
#define MOTOR2_A_PIN 	GPIO_PIN_1
#define MOTOR2_B_PIN 	GPIO_PIN_0

//=========================================== ENCODER ===========================================

#define ENCODER1_A_PORT 	GPIOB
#define ENCODER1_B_PORT 	GPIOB
#define ENCODER2_B_PORT 	GPIOB
#define ENCODER2_A_PORT 	GPIOA
#define ENCODER1_A_PIN 		GPIO_PIN_4
#define ENCODER1_B_PIN 		GPIO_PIN_5
#define ENCODER2_A_PIN 		GPIO_PIN_15
#define ENCODER2_B_PIN 		GPIO_PIN_3

#define ENCODER_CYCLE 		48960
#define ENCODER1_COUNTER 	TIM3->CNT
#define ENCODER2_COUNTER 	TIM2->CNT
#define MOTOR1_PWM 			TIM8->CCR1
#define MOTOR2_PWM 			TIM8->CCR2

//=========================================== UltraSonic ========================================

#define US1_TRIG_PORT		GPIOE
#define US2_TRIG_PORT		GPIOE
#define US3_TRIG_PORT		GPIOE
#define US4_TRIG_PORT		GPIOE

#define US1_TRIG_PIN		GPIO_PIN_0
#define US2_TRIG_PIN		GPIO_PIN_1
#define US3_TRIG_PIN		GPIO_PIN_3
#define US4_TRIG_PIN		GPIO_PIN_4



#define rad2deg 57.2958f

#define Speed2PWM_Rate (float)(75/218)
#define Tick2RPM_Rate 0.1225

#define ULTRASONIC_UNITS	4

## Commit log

2023-07-24 [add] altium schematics and pcb
    Here are the schematics used for this project. The microcontroller unit (MCU) used is an STM32F407VGT6. The following peripherals are utilized on this board:
    - Ethernet: Physical layer uses the dp83848, and the RJ45 connector is HR911105A.
    - USB to TTL: A CH340G chip is used with a USB type B connector, which can also power up the board when the 12V power supply is not available.
    - Motor driver: An L298 motor driver is used for two JGA25 motors.
    - Others: There are 4 XH connectors for connecting 4 HC-SR04 modules externally. Additionally, there is an XH connector for the GY-80 IMU module. Some peripherals are used as GPIO outputs for additio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
    -P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
    [ETHERNET.SchDoc, L298.SchDoc, LMR_V1.PrjPcb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]
2023-07-24 [Add] PCB file for the project
    PCB file for the said schematics was drafted
2023-08-20 modified major issues
    - AMS1117 : changed the TAB pad from connecting to ground to VDD MCU
    - BOOT : Pulled down instead of pull up
    [L298.SchDoc, Micro.SchDoc]
2023-08-20 modified major issues
    - modified problems with micro schematic
    [LMR_V1.PrjPcb, Micro.SchDoc]
2023-08-20 [Edit] problems with driver and added fan
    - thickening driver motor track
    - added fan for driver
    [L298.SchDoc, LMR_V1.PrjPcb, Micro.SchDoc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]
2023-08-22 [edit] minor changes
    [LMR_V1.PrjPcb, Power_1.SchDoc]
2023-08-22 [Add] ADC pin added for battery management
    ADC Pin : added for reading battery level and safety purposes PA5 pin
2023-09-27 :sparkles: [add] : pinouts of LMR.V.1.1
    Board layout.ioc : this involves the naming and definition of the pinouts of STM32f407VGT6 used on our robot LMR
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2023-10-11 :sparkles: [ADD} : ioc file and code generation
    this is the main layout for Bardia MCU board on Lenna Robotics LMR_V1.1
2023-10-11 :sparkles: [ADD] : board pinout definition header file
    Header file for Bardia board MCU this is our reference on our project
2023-10-18 :sparkles: [ADD] : added ultrasonic library
    this script might have some issues in LMR_Delayus function
    the whole process should be checked again
    [Lenna-Bardia-MCU-Board.ioc, main.c, mcu_layout.h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]
2023-11-18 🎨 [REFACTOR] : Ultrasonic Library Standards and Structure
    This commit focuses on enhancing the ultrasonic library's structure, performance, and code formatting while maintaining its general API behavior. The following highlights summarize the changes made:
    - Use of struct data types for sensor configuration parameters
    - Improve formatting and code structure
    - Modular and easy-to-modify functions
    🚧 Note: This module is currently provided and tested for a single ultrasonic sensor connected to the MCU board. Scripts for handling multiple ultrasonic sensors will be developed soon.
    The "ultrasonic" library provides four main functions for operating HC-SRF04 ultrasonic sensors or similar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
2023-11-18 ✨ [ADD] : Utility for microsecond time delays
    Introducing the "utilities.h" module for essential but diverse functionalities, including microsecond time delays.
    This commit adds the "utilities.h" module, which provides necessary functionalities, such as microsecond time delays. Currently, the module consists of two main functions:
    LRL_Delay_Init: Initializes the time delay functionality.
    LRL_Delay_Us: Applies a microsecond delay.
    🚧 Note: Please be aware that the current implementation utilizes TIMER 1 for time delays. Any changes to the timer number or other configurations will require modifications within the code.
2023-11-22 :sparkles: [ADD] : first simulation results
    .slx file: simulink blocks for the kinematics of the differential drive robot obtained derived by the kinematic equation given for the differential drive robot
    .m file : this is the matlab code for first analyzing the output results on simulink and on the second section it is the code version of simulink blocks to double check the results.
    on this version we understood that there is an offset between y and x but we dont know the reason yet. if we understand the reason we will update the repository
2023-12-11 ✨ [ADD] : Basic Implementation of the Motion Control Header
    This commit introduces a modular script to facilitate usage on various microcontrollers and future variations/updates of the LENNA MCU Board. To define a motor, utilize the struct motor_cfgType which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
    typedef struct
    {
    GPIO_TypeDef * MOTOR_1_GPIO;
    uint16_t MOTOR_1_PIN;
    GPIO_TypeDef * MOTOR_2_GPIO;
    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
2023-12-13 :sparkles: [ADD] : first motion feedback plot simulation
    this simulink file is used to plot the step response of the DC motor of the LMR.
    since this attempt is solely purposed on plotting the step response at the initial stage the .slx file is not very detailed and the description written in the file is of enough help to understand the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
2024-01-28 📝 [DOC] : Investigating Motor Driver Design and Control
    Attempted to identify the motor's dynamics equations based on its step response. However, it became apparent that the motor does not exhibit a linear characteristic. Notably, the motor reaches its ul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
    To investigate further, we initially identified the system using a 100% duty cycle, which represents the motor's step response. Subsequently, we simulated the system with PWM inp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
2024-02-26 :sparkles: [ADD] : modified identification in simulink and stm32
    - added input speed in simulink and stm32 code
    - identified transfer function
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2024-03-12 :sparkles: [ADD] : finalizing STM32 UART transmit and receive and PID coefficients in MATLAB
    - making changes so the UART RX and TX doesn't effect the outcome by making them work in the same rate with interrupt usage
    - finding PID coefficients such that we get an acceptable result
    *** Be careful ***
    the delay in STM32 code HAL_Delay(10) makes the delay rate the same as sampling time don't play with it if you want to change the code put it in interrupt and use int instead of uint in matlab because numbers may get negative.
    [main.c]
2024-03-24 :sparkles: [ADD] : PID controller Initial Commit
    PID control STM32 Library first commit
    there are a few problems to be solved like the problem with the data type of the control signal that should be corrected otherwise the code is not bad and seems to work for single motor
    [main.c, main.h, pid.c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]
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2024-03-29 :sparkle: [FEATURE]: enhance pid
    - now pid calculation is correct and tested in real life
    - Anti wind up working properly
    - next change should be the direction
    [main.c, main.h, pid.c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]
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2024-06-02 🎨 [ART] : Folder structure re-organized
    [ETHERNET.SchDoc, L298.SchDoc, LMR_V1.PrjPcb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]
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2024-06-03 :bug: [FIX] : fix robot angle measurements using complementary filter
    [main.c, odometry.c]
2026-07-26 🔧 major fix on PID implementation
    [main.c, pid.c, pid.h]
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2026-08-11 🚑 hotfix for jetson communication problem
    The problem was that jetson was IMU polling was taking a lot of time and it was blocking it is now in main and is performed every 100ms to keep the effect to a minimum
    [main.c, rosserial.c]
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

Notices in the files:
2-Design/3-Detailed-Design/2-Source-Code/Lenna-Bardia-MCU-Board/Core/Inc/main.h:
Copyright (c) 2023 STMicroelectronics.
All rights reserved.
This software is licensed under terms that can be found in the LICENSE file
